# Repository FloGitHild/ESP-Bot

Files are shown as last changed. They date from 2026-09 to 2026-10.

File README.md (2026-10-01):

# ESP32-Kettenroboter

Ein modularer Kettenroboter als MINT-Lernprojekt: Schülerinnen und Schüler
sollen Aufbau, Sensorik und Programmierung eines mobilen Roboters kennenlernen.
Das Projekt verbindet ein Robotik-Konzept mit KiCad-Entwürfen und ersten
Arduino-Testprogrammen.

> **Projektstand:** Dieses Repository dokumentiert ein Konzept und begonnene
> Hardware-Entwicklung. Die beschriebenen Funktionen sind nicht automatisch
> als fertig aufgebaut, vollständig programmiert oder praktisch validiert zu
> verstehen. Insbesondere ist hier noch keine vollständige Fahr- und
> Autonomiesoftware enthalten.

## Konzept

Der geplante Roboter soll Hindernisse erkennen, Linien verfolgen, Abstände und
Fahrdaten erfassen und Daten per WLAN weitergeben. Das Konzept sieht vor, bis zu
20 möglichst gleiche Einheiten für den MINT-Unterricht aufzubauen.

Wesentliche Bausteine der beschriebenen Architektur:

- **Zwei Controller:** Ein ESP32-WROOM-32E übernimmt die übergeordnete Logik,
  Sensorik und WLAN-Kommunikation. Ein Arduino Pro Micro ist für zeitkritische
  Motorsteuerung, Encoder und Signaltöne vorgesehen.
- **Kettenantrieb:** Zwei N20-Getriebemotoren mit Encodern werden über einen
  Motortreiber angesteuert.
- **Sensorik:** Ein HC-SR04 für die Hinderniserkennung vorn, zwei VL53L0X für
  seitliche Abstandsmessung, ein TCS34725 für die Linienerkennung und eine
  LSM6DSOX-IMU für Beschleunigungs- und Drehratenmessung.
- **Erweiterbarer I²C-Bus:** Ein TCA/PCA9548A-Multiplexer soll Sensoren mit
  gleicher I²C-Adresse voneinander trennen. Ein zusätzlicher Anschluss am
  Gehäusedeckel ist für externe I²C-Module vorgesehen.
- **Rückmeldung und Aufzeichnung:** OLED, WS2812-LEDs und Piezo dienen der
  Ausgabe; eine microSD-Karte ist für Sensor- und Fahrdaten vorgesehen.
- **Energieversorgung:** Das Konzept beschreibt einen 1S-LiPo-Akku mit
  getrennten Boost-Versorgungen für Motoren und Logik.

Die detaillierte Beschreibung, Pin- und Busbelegungen, Stückliste sowie
Kostenschätzungen stehen in den Konzeptunterlagen. Werte daraus sind
Planungsangaben und müssen vor dem Aufbau anhand der verwendeten Bauteile
überprüft werden.

## Inhalt des Repositorys

| Pfad | Inhalt |
| --- | --- |
| [`Kettenroboter_Konzept_V1.0.html`](Kettenroboter_Konzept_V1.0.html) | Ausführliche Konzeptbeschreibung mit Architektur, Sensorik, Versorgung, Pinplan und Kalkulation |
| [`Kettenroboter_Konzept_V1.0.docx`](Kettenroboter_Konzept_V1.0.docx) | Bearbeitbare Fassung des Konzepts |
| [`Kettenroboter - Konzept V1.0.pdf`](Kettenroboter%20-%20Konzept%20V1.0.pdf) | PDF-Fassung des Konzepts |
| [`KICAD/Platine_V1.0/`](KICAD/Platine_V1.0/) | KiCad-Schaltplan- und Platinenprojekt V1.0 |
| [`Arduino Codes/`](Arduino%20Codes/) | Arduino-Sketche für einzelne Hardwaretests |
| [`Datenblätter/`](Datenbl%C3%A4tter/) | Datenblätter und ESP32-Maßzeichnung |
| [`Teilliste.xlsx`](Teilliste.xlsx) | Bauteil- und Bestellübersicht |
| [`Neue Notiz 09-22-2026.pdf`](Neue%20Notiz%2009-22-2026.pdf) | Zusätzliche Projektnotiz |

## Arduino-Testsketche

Die Sketche testen einzelne Baugruppen und sind kein zusammenhängendes
Roboterprogramm:

| Sketch | Zweck |
| --- | --- |
| [`IIC_Bus_Scanner.ino`](Arduino%20Codes/IIC_Bus_Scanner/IIC_Bus_Scanner.ino) | Sucht I²C-Geräte direkt und an den Kanälen eines Multiplexers |
| [`IIC_MUX_Test.ino`](Arduino%20Codes/IIC_MUX_Test/IIC_MUX_Test.ino) | Prüft Multiplexer, Buspegel und Kanalwahl |
| [`MUX_Test.ino`](Arduino%20Codes/MUX_Test/MUX_Test.ino) | Weiterer Multiplexer-Test |
| [`OLED_Direct_Test.ino`](Arduino%20Codes/OLED_Direct_Test/OLED_Direct_Test.ino) | Initialisiert ein OLED und zeigt Beispieltexte an |

Die Sketche verwenden derzeit SDA an GPIO 15 und SCL an GPIO 16. Im
Konzept-Pinplan ist der I²C-Hauptbus dagegen auf GPIO 21/22 vorgesehen.
Vor dem Anschließen oder Ausführen daher die tatsächliche Verdrahtung, den
jeweiligen Sketch und den passenden ESP32-Pinplan miteinander abgleichen.
Der OLED-Test verwendet die Bibliothek **Adafruit_SSD1306**.

## Sicherheit und Prüfung

Der Entwurf umfasst einen Lithium-Polymer-Akku, Ladeelektronik, DC/DC-Wandler
und Motoren. Vor einem Aufbau oder Ladebetrieb müssen insbesondere Akku,
Ladeschaltung, Schutzfunktionen, Leitungsquerschnitte und Strombelastbarkeit
für die tatsächlich ausgewählten Komponenten geprüft werden. Lithium-Akkus
nicht unbeaufsichtigt oder entgegen den Herstellerangaben laden.

ESP32-GPIOs sind nicht 5-V-tolerant. Für den im Konzept vorgesehenen HC-SR04
muss insbesondere das Echo-Signal auf einen zulässigen ESP32-Pegel angepasst
werden. Maßgeblich sind die Datenblätter der konkret eingesetzten Bauteile.

## Urheberschaft und Nutzung

Die eigenen Projektideen, konzeptionellen Entscheidungen und Ausarbeitungen
dieses Projekts stammen von **Florian (GitHub: [FloGitHild](https://github.com/FloGitHild))**.
Sie dürfen nur verwendet, bearbeitet oder weiterverbreitet werden, wenn
**Florian (FloGitHild) klar als Urheber genannt wird**. Eine Nutzung ohne diese
Namensnennung ist nicht gestattet.

Die Namensnennung ist keine pauschale Lizenz für Inhalte Dritter. Datenblätter,
Herstellerangaben, Produktnamen und sonstige übernommene Materialien
unterliegen weiterhin den Rechten und Bedingungen ihrer jeweiligen
Rechteinhaber. Für solche Inhalte gelten die jeweiligen Lizenz- und
Nutzungsbedingungen.

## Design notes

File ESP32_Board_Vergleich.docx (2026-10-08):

# ESP32-Boards im Vergleich – Auswahl für den Kettenroboter

Ziel: Ein gängiges, in Serie (ab 100 Stück) beschaffbares ESP32-Board finden, das neben der bestehenden Sensorik (HC-SR04, 2× VL53L0X, TCS34725, LSM6DSOX, OLED, microSD, WS2812, I²C-Multiplexer) noch Reserven für Erweiterungen hat: zweites Kameramodul, 5-Achsen-Roboterarm, weitere Farbsensoren und zusätzliche Mikrocontroller am I²C-Bus.

# 1. Anforderungen aus dem Konzept

- WLAN-Kommunikation (Datenübertragung), Bluetooth optional.
- Mehrere I²C-Geräte (Multiplexer TCA/PCA9548A, Sensoren, OLED, externe Module, weitere Mikrocontroller).
- SPI für microSD, 1-Wire-ähnliche Datenleitung für WS2812, Trigger/Echo für HC-SR04, Piezo, UART zum Arduino Pro Micro.
- Reserve-GPIOs und Rechenleistung für Kamera(s) und Servo-/Arm-Steuerung (z. B. über PCA9685 am I²C).
- Verfügbarkeit in großen Stückzahlen (20 Roboter plus Ersatz, Ziel: 100 Stück) zu einem für den Unterricht tragbaren Preis.

# 2. Vergleichstabelle gängiger ESP32-Boards

Board | SoC / Modul | CPU | Flash / PSRAM | Funk | Nutzbare GPIO* | Kamera | USB / Besonderheit | Eignung für Erweiterungen | Preis/Stk. bei ~100 Stk.**
ESP32-DevKitC V4 (WROOM-32E) – im Konzept vorgesehen | ESP32 (WROOM-32E) | 2× Xtensa LX6, 240 MHz | 4 MB / – | WLAN b/g/n, BT 4.2 + BLE | ~25 | Nur extern (I2S/Parallel, umständlich) | USB-UART (CP2102), 38 Pins, Standard-Footprint | Gut für aktuelles Konzept; wenig RAM (520 KB), knapp für Kamera | ca. 4–9 € (Klone 3–5 €, Original Espressif 8–10 €)
ESP32-DevKitC-VE (WROVER-E) | ESP32 (WROVER-E) | 2× LX6, 240 MHz | 4–8 MB / 8 MB | WLAN b/g/n, BT 4.2 + BLE | ~22 (GPIO16/17 für PSRAM belegt) | Ja (OV2640 möglich) | Pinkompatibel zu DevKitC V4 | Gut: PSRAM für Bildpuffer, gleiche Platine nutzbar | ca. 9–14 €
ESP32 DevKit V1 (DOIT, 30/38 Pin, Klon) | ESP32 (WROOM-32) | 2× LX6, 240 MHz | 4 MB / – | WLAN b/g/n, BT 4.2 + BLE | ~25 | Nein | USB-UART (CP2102/CH340); Qualität schwankt | Wie DevKitC, günstig, aber uneinheitliche Pinouts/Qualität | ca. 3–5 €
ESP32-S3-DevKitC-1 (N8R8 / N16R8) | ESP32-S3 (WROOM-1) | 2× Xtensa LX7, 240 MHz, Vektorbefehle (KI) | 8–16 MB / 8 MB (Octal) | WLAN b/g/n, BT 5 (LE) | ~30 (GPIO 35–37 bei Octal-PSRAM belegt) | Ja (DVP-Kameraschnittstelle, OV2640/OV5640) | 2× USB-C (nativ + UART), 44 Pins | Sehr gut: viel RAM, schnell, mehr Peripherie | ca. 7–15 € (Klone 6–9 €, Original 10–15 €)
Seeed XIAO ESP32S3 Sense | ESP32-S3 | 2× LX7, 240 MHz | 8 MB / 8 MB | WLAN, BT 5 | ~11 (kleine Bauform) | OV2640 mit Mikro, steckbar | USB-C, LiPo-Laden, 21×17,8 mm | Gut als zusätzliches Kameramodul; zu wenig Pins als Hauptcontroller | ca. 12–16 €
ESP32-S3-CAM (z. B. Freenove / Generic N16R8) | ESP32-S3 (WROOM-1) | 2× LX7, 240 MHz | 16 MB / 8 MB | WLAN, BT 5 | ~10 frei | OV2640/OV5640 integriert | USB-C, microSD-Slot | Ideal als 2. Kameramodul (I²C/UART-Slave), nicht als Hauptboard | ca. 10–18 €
ESP32-CAM (AI Thinker) | ESP32 (WROVER) | 2× LX6, 240 MHz | 4 MB / 4 MB | WLAN, BT 4.2 | ~8 frei (SD teilt Pins) | OV2640 | Kein USB (Programmieradapter nötig), microSD | Nur als Zusatz-Kameramodul; Programmierung aufwändig | ca. 5–9 €
ESP32-C3-DevKitM-1 / Super Mini | ESP32-C3 | 1× RISC-V, 160 MHz | 4 MB / – | WLAN, BT 5 (LE) | ~13 | Nein | USB nativ (Serial/JTAG), sehr klein | Zu schwach/wenig Pins für Hauptcontroller; gut als Sensor-Nebenknoten | ca. 2–5 €
ESP32-S2 Mini / DevKitM-1U | ESP32-S2 | 1× LX7, 240 MHz | 4 MB / 2 MB | Nur WLAN (kein BT) | ~28 | Eingeschränkt | USB OTG nativ | Veraltet gegenüber S3, nur für Sparprojekte | ca. 3–6 €
ESP32-C6-DevKitC-1 | ESP32-C6 | 1× RISC-V, 160 MHz (+LP-Kern) | 8 MB / – | WLAN 6 (ax), BT 5, Zigbee/Thread | ~22 | Nein | 2× USB-C | Modern, aber nur ein Kern und kein PSRAM; keine Kamera | ca. 7–11 €
LOLIN S3 / S3 Pro (WEMOS) | ESP32-S3 | 2× LX7, 240 MHz | 16 MB / 8 MB | WLAN, BT 5 | ~25 | Ja | USB-C, LiPo-Ladeschaltung, Qwiic/Stemma-Stecker (S3 Pro) | Sehr gut: ähnlich DevKitC-1, plus Akkuladen, Steckverbinder | ca. 8–13 €
Adafruit Feather ESP32 V2 / ESP32-S3 | ESP32 / ESP32-S3 | LX6 oder 2× LX7 | 8 MB / 2 MB (V2: 2 MB PSRAM) | WLAN, BT | ~21 | Nein (extern) | LiPo-Laden, STEMMA-QT, Hochwertig | Gut, aber teuer; Mengenpreis für 100 Stk. kaum günstiger | ca. 15–22 €

* Ungefähre Anzahl frei nutzbarer GPIOs ohne Flash/PSRAM/Boot-Pins, die je nach Variante abweichen.
** Richtwerte netto, Stand der Marktrecherche (Annahme: Bestellung ab 100 Stück über Distributoren wie Mouser, DigiKey, LCSC, Berrybase, Eckstein oder direkt bei Herstellern/AliExpress). Preise schwanken stark und sind vor Bestellung per Angebot zu prüfen. Grün markiert: Empfehlung.

# 3. Preisspannen im Überblick (Einzelboard, ~100 Stück)

Kategorie | Preisspanne | Boards
Budget (Klone, Standard-ESP32) | ca. 2–6 € | DevKit V1, DevKitC-Klone, C3 Super Mini, S2 Mini
Mittelklasse (Original/gute Klone, S3) | ca. 6–15 € | DevKitC V4, DevKitC-VE, S3-DevKitC-1, C6-DevKitC-1, LOLIN S3, ESP32-CAM, S3-CAM
Premium (Marken, Zusatzfunktionen) | ca. 12–22 € | XIAO ESP32S3 Sense, Adafruit Feather

Bei 20 Robotern entspricht das einem Mehrpreis von rund 100–200 € Gesamtkosten für ein S3-Board anstelle des WROOM-32E – bei deutlich mehr Leistungsreserven.

# 4. Kernunterschiede

- ESP32 (klassisch, WROOM/WROVER): Zwei Kerne mit 240 MHz, sehr verbreitet, viele Bibliotheken, 520 KB RAM. Ohne PSRAM sind Kameras kaum sinnvoll, mit WROVER aber möglich. Bluetooth Classic nur hier.
- ESP32-S3: Schneller Dual-Core (LX7) mit KI-Vektorbefehlen, natives USB, BT 5, bis zu 16 MB Flash und 8 MB Octal-PSRAM, hardwareseitige Kameraschnittstelle sowie mehr GPIOs. Deutlich bessere Wahl für Kamera und Multitasking.
- ESP32-C3 / C6: Einkern-RISC-V, günstig, modern (BT 5, WLAN 6 beim C6), aber ohne Kamera-Eignung und mit weniger Pins. Geeignet als Nebenknoten, nicht als Hauptcontroller.
- ESP32-S2: Nur WLAN, Einkern; durch S3 praktisch überholt.
- Kamera-Boards (ESP32-CAM, S3-CAM, XIAO Sense): Kompakt mit Sensor, aber kaum freie Pins – ideal als separate Kameramodule, die per UART/I²C/WLAN Daten liefern.
- Qualität: Originale (Espressif, Seeed, Adafruit) sind bei 100 Stück meist nur 10–30 % teurer als Klone, dafür einheitlicher (Pinout, Spannungsregler, USB-Chip) – wichtig für 20 baugleiche Roboter.

# 5. Fazit und Empfehlung

Empfehlung: ESP32-S3-DevKitC-1-N16R8 (Espressif, ESP32-S3-WROOM-1, 16 MB Flash, 8 MB Octal-PSRAM). Alternativ gleichwertig: LOLIN S3 (16 MB / 8 MB). Richtpreis: ca. 7–15 € pro Stück bei 100 Stück.

Warum dieses Board?

- Leistung: Dual-Core 240 MHz, 8 MB PSRAM – genug für Kamerabild, WLAN-Streaming, Datenlogging und Sensorfusion parallel.
- Kamera: Native DVP-Kameraschnittstelle; eine Kamera direkt am Board, eine zweite als eigenständiges Kameramodul (ESP32-S3-CAM oder XIAO Sense), das per WLAN, UART oder I²C angebunden wird.
- Roboterarm (5 Achsen): Servos über einen PCA9685 (16-Kanal-PWM, I²C) ansteuern – nur zwei GPIOs am ESP32 nötig. Servos benötigen eine eigene 5–6-V-Versorgung mit ausreichend Strom (nicht über den Board-Regler).
- Farbsensoren und weitere I²C-Geräte: Über den bereits geplanten TCA9548A lassen sich 8 Kanäle mit je eigenen gleichen Adressen betreiben; der S3 bietet zwei I²C-Controller und kann zusätzlich als Master für weitere Mikrocontroller dienen.
- Weitere Mikrocontroller: Arduino Pro Micro (bereits vorgesehen) per UART; weitere Knoten per I²C (ESP32 als Master) oder WLAN/ESP-NOW.
- Zukunftssicher: BT 5, natives USB (Debugging und Programmierung ohne Zusatzchip), breite Community-Unterstützung.

Wichtige Hinweise zur Umsetzung:

- Der S3-DevKitC-1 hat ein anderes Pinout und eine andere Bauform (2×22 Pins) als der DevKitC V4 – die KiCad-Platine müsste angepasst werden. Wer die vorhandene Platine unverändert nutzen will, wählt das ESP32-DevKitC-VE (WROVER-E, ca. 9–14 €) mit PSRAM, behält aber nur die ältere Kernarchitektur.
- Bei den Octal-PSRAM-Varianten (N8R8, N16R8) sind GPIO 35, 36 und 37 intern belegt und nicht nutzbar; Pinbelegung vor dem Platinen-Redesign anhand der Espressif-Dokumentation prüfen.
- Strombedarf: WLAN-Spitzen mit Kamera können über 500 mA erreichen; Logikversorgung (Boost aus 1S-LiPo) entsprechend dimensionieren.
- Vor der Großbestellung 2–3 Muster verschiedener Lieferanten testen und ein verbindliches Angebot für 100 Stück einholen.

Hinweis: Die Preise sind Richtwerte aus allgemeiner Marktkenntnis, nicht aus einer tagesaktuellen Abfrage, und ändern sich häufig.

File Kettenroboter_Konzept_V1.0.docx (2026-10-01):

# Kettenroboter mit ESP32-WROOM-32E

Konzept V1.0 - Idee · Aufbau · Teilliste · Datenblatt

Stand: 28.09.2026 · Bestellung: Dezember 2026 · 20 Stück · 1S LiPo 3,7V 10.000mAh (Fertig-Pack) · Prototyp V1.0

# 1. Idee

## 1.1 Was soll der Roboter können?

Ein Kettenroboter für den MINT-Unterricht, der selbstständig Hindernisse erkennt, Linien folgt, Strecken misst und über WiFi Daten weitergibt. 20 identische Einheiten sollen gebaut und programmiert werden – jeder Schüler erhält einen Roboter zum Selbstbau.

- Hinderniserkennung vorn: HC-SR04 Ultraschall misst 3-400cm über Trig/Echo-Puls – Schüler lernen Schallgeschwindigkeit und Laufzeitberechnung
- Abstand seitlich: 2× VL53L0X ToF (links/rechts) für Wandabstand und Linienführung
- Linienverfolgung: TCS34725 Farbsensor erkennt schwarze Linien auf hellem Untergrund
- Erweiterung: 4-pol. I²C-Buchse an der Oberfläche (Deckel) führt den Bus nach außen – externe Module (BME280 etc.) einfach einstecken, freier MUX-Kanal K5
- Lage/Drift: LSM6DSOX IMU (Beschleunigung + Gyroskop) für Selbstausrichtung
- Steuerung: ESP32 (WiFi, Logik, Sensorik) + Arduino Pro Micro (Echtzeit: Motor-PWM, Encoder, Töne)
- Feedback: WS2812 LED-Strip (Statuslicht) + OLED-Display (Messwerte) + Piezo (Signaltöne)
- Datenaufzeichnung: microSD-Karte speichert Sensor- und Fahrdaten

## 1.2 Warum diese Architektur?

Entscheidung | Begründung | Lerninhalt
ESP32 + Arduino (zwei CPUs) | ESP32 für WiFi/Sensorik, Arduino für Echtzeit-Motorsteuerung | Arbeitsteilung, I²C-Kommunikation, Adressierung
I²C-Bus mit TCA9548A | Alle Sensoren an 2 Pins, trotz gleicher Adressen | Bussysteme, Multiplexer, Adresskonflikte
Ultraschall (HC-SR04) statt ToF vorn | Direkte GPIO-Ansteuerung, kein Chip nötig | Laufzeitmessung, Schallgeschwindigkeit, PWM
1S LiPo 3,7V 10Ah (Fertig-Pack) | Einzelzelle = kein Zellausgleich, keine Balance-Ladung, einfachste Lithium-Technik – 10Ah trotzdem ~6-7h Laufzeit | Lithium-Sicherheit, CC/CV-Laden, Kapazität vs. Laufzeit
2× MT3608 Boost (6V + 5V) | Aus 3,0-4,2V konstant 6V für Motoren und 5V für Logik – unabhängig vom Akkustand, Eingang ab 2V (bis tief in die Entladung) | DC/DC-Wandler (Boost statt Buck), Poti-Einstellung, Effizienz
DRV8833 Treiber | Fast ohne Spannungsabfall (360mΩ) → 6V kommen am Motor an, 95% Effizienz, kein Kühlkörper | H-Brücke, PWM, Freilauf/Bremse
TP4056 USB-C Lademodul | CC/CV-Ladung 4,2V/1A mit Schutzschaltung (Über-/Unterladung, Kurzschluss) – 0,59€ ab 20 Stück, Laden per handelsüblichem USB-C | CC/CV-Ladephasen, Ladestrom vs. Kapazität (0,1C), Schutzschaltungen
Female-Header | Alle 24 freien GPIOs steckbar – kein Löten für Addons | Erweiterbarkeit, Pinbelegung

## 1.3 Steckdose auf einen Blick

ESP32-WROOM-32E (WiFi+BT) + Arduino Pro Micro (Echtzeit)

I²C (IO21/IO22) · SPI (IO18/19/23/26) · GPIO (IO16/17) · I²C-Port am Deckel (K5)

2× N20 6V 1000RPM + DRV8833 (6V vom Boost → ~6V am Motor)

HC-SR04 · 2× VL53L0X · TCS34725 · LSM6DSOX · OLED

1S LiPo 3,7V 10Ah → 2× MT3608 Boost (6V/5V) → alles · Lader: USB-C TP4056

24 GPIOs auf Female-Header für Addons

ca. 160 × 160 × 100 mm

ca. 800 g (geschätzt)

# 2. Aufbau

## 2.1 Stromversorgung (Schaltplan)

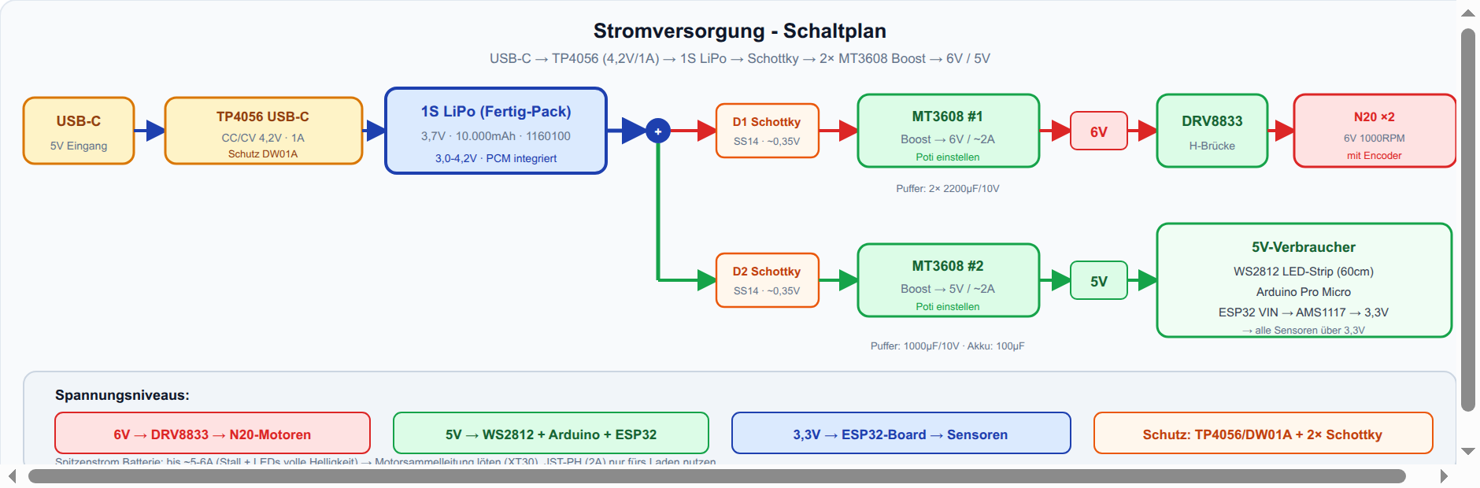
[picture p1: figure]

- Ladung:TP4056 USB-C Lademodul (https://www.roboter-bausatz.de/p/tp4056-1a-lithium-ionen-lipo-lademodul-fuer-arduino-usb-c) (CC/CV, 4,2V/1A, integrierter DW01A-Schutz: Über-/Unterladung + Kurzschluss; rot=lädt, grün=voll). Staffelpreis: 0,59€ ab 20 Stück – Alternativen: makeroo 3er-Set 1,79€ (https://makeroo.de/products/3er-set-tp4056-5v-1a-usb-c-lademodul-18650-lithium-akkuladeboard-mit-schutzschaltung), Pollin 1,75€ ab 10 (https://www.pollin.de/p/daypower-lademodul-fuer-lithium-akkus-m-ll-tp4056-351427). Bei 1S entfallen Balance-Ladung und Zellausgleich komplett.
- Akku: 1× flache Zelle 3,7V 10.000mAh (1160100, 11×60×100mm) mit integrierter PCM-Schutzplatine, ~160-200g. Einzelzelle = keine Reihenschaltung, keine BMS-Balancelogik nötig. Vorsicht: die JST-PH-Steckverbindung ist nur fürs Laden geeignet (2A) – Motorsammelleitung direkt löten oder XT30 verwenden (Spitzen bis ~6A).
- 6V Boost: MT3608 (Eingang 2-24V, internes 4A-Schaltstrom-Limit, ~93% Wirkungsgrad) lädt die Ausgangs-Spannung auf konstant 6V – Motoren laufen unabhängig vom Akkustand. Durch den geringen Abfall des DRV8833 (360mΩ) kommen ~5,7-6V am Motor an → volles Drehmoment. Kein Kühlkörper nötig.
- 5V Boost: zweiter MT3608 → WS2812, Arduino und ESP32-VIN. Das ESP32-Board wandelt intern (AMS1117) auf 3,3V für sich und alle Sensoren.
- Puffer-Kondensatoren: 2× 2200µF/10V (6V-Schiene), 1000µF/10V (5V-Schiene), 100µF (Akku) glätten die ms-weisen Lastspitzen von PWM/Motoren – ΔV = I·t/C, also ~5ms Puffer bei 1A und 4700µF. Der Boost selbst regelt die Sekundenlast; die Kondensatoren fangen nur die Schaltspitzen ab.
- Schottky-Dioden (D1/D2): 2× SS14 (1A/40V) oder SS54 (5A) zwischen Akku und den Boost-Eingängen – Polaritäts- und Ladeschutz, Entkopplung der Schienen. Der ~0,35V Abfall ist unkritisch, da der MT3608 schon ab 2V Eingang arbeitet (auch tief entladene Zelle 3,0V − 0,35V = 2,65V).
- Nicht genutzt – und warum: XL6009-Booster brauchen laut Datenblatt ≥3,6V Eingang und würden schon vor Ende der Entladung abschalten; Buck-Wandler (MP2338, LM2596) wären die falsche Topologie, da die Zelle unter der Rails-Spannung liegt. Bei 1S ist Boost die einzige sinnvolle Wahl.

Die PCM der Zelle und der DW01A des Lademoduls begrenzen den Entladestrom typischerweise auf 2-3A. Beim Starrfahren können die Motorspitzen darüber liegen – die Schutzschaltung schaltet kurz ab und erholt sich lastfrei (schützendes Verhalten, kein Schaden). Alternativ: Pack mit höherer PCM-Schwelle wählen oder Motorstrom per PWM begrenzen. Zusätzlich begrenzt der MT3608 (4A-Schaltstrom) und die DRV8833-Überlastschaltung den Strom – es kann also nichts durchbrennen, die Motoren werden im Worst Case nur weich abgebremst.

## 2.2 Bus-Architektur (I²C + SPI + GPIO)

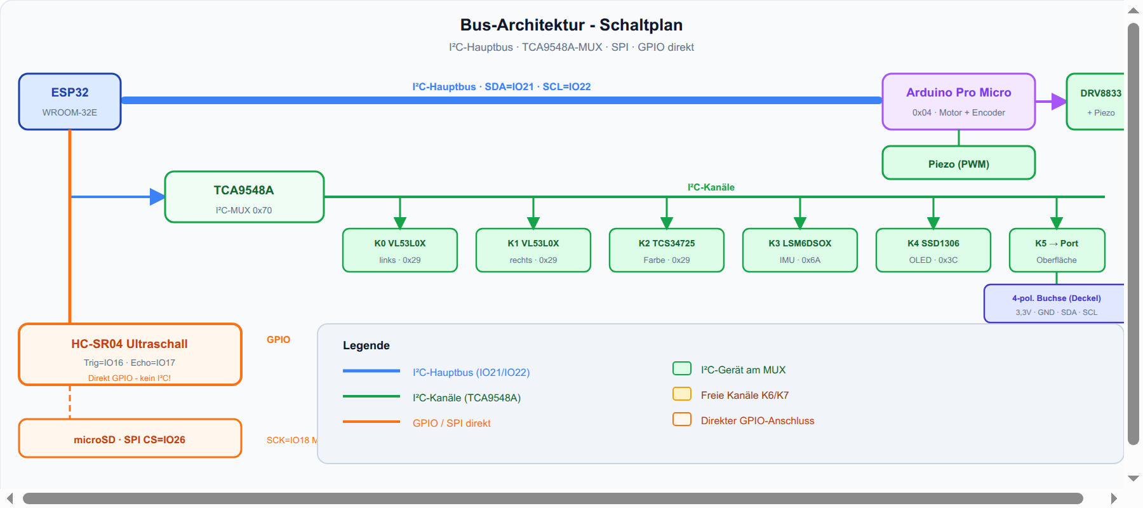
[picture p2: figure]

I²C-Adressen: TCA9548A=0x70 · VL53L0X=0x29 (K0+K1) · TCS34725=0x29 (K2) · LSM6DSOX=0x6A (K3) · SSD1306=0x3C (K4). Nicht belegt: z.B. 0x20-0x28, 0x38-0x3B, 0x3D-0x3F, 0x6B-0x6F, 0x71-0x77. HC-SR04: kein I²C - direkt GPIO, 40kHz, 3-400cm; Echo kommt mit 5V → Spannungsteiler 10kΩ/20kΩ vor IO17 (ESP32-GPIOs sind nicht 5V-tolerant!).

Versorgung: Alle I²C-Sensoren laufen mit 3,3V direkt vom ESP32-Board (Board-Regler AMS1117, Eingang 5V) – Gesamtverbrauch nur ~60mA, daher ist kein dritter Wandler nötig. Ein separater 3,3V-Wandler wäre nur nötig bei >800mA Sensorlast oder als entkoppelte Rausch-Schiene.

Oberflächen-Port (K5): 4-pol. Buchse auf dem Deckel (3,3V · GND · SDA · SCL) führt den I²C-Bus nach außen – für externe Module (BME280, Lichtsensor, Erweiterungen) ohne Löten. Angeschlossen an den freien MUX-Kanal K5: externe Geräte sind vom Hauptbus isoliert, daher keine Adresskonflikte mit den Bord-Sensoren (gleiche Adresse 0x29 z.B. möglich). Software: tca.selectChannel(5). K6/K7 bleiben zusätzlich frei. Alternative Verdrahtung: Port direkt auf IO21/IO22 (Hauptbus) – dann nur Geräte ohne Adresskonflikt verwenden.

## 2.3 Pin-Plan ESP32 (34 GPIO)

### Feste Belegung (10 Pins)

GPIO | Funktion | GPIO | Funktion
IO21 | I2C SDA (alle Sensoren, OLED) | IO22 | I2C SCL
IO18 | SPI SCK (microSD) | IO19 | SPI MISO
IO23 | SPI MOSI | IO26 | SPI CS_SD
IO1 | WS2812-Daten | IO5 | Strapping (digital)
IO16 | HC-SR04 Trig | IO17 | HC-SR04 Echo (über Spannungsteiler 10kΩ/20kΩ!)

### Encoder + Motor → Arduino Pro Micro

Arduino Pin | Funktion | Bemerkung
Pin 2, 4 | Encoder 1 A/B | HAT-Interrupt + PCINT
Pin 7, 8 | Encoder 2 A/B | PCINT
Pin 3, 6 | DRV8833 AIN1 / AIN2 (Motor links) | PWM: Richtung + Geschwindigkeit
Pin 5, 9 | DRV8833 BIN1 / BIN2 (Motor rechts) | PWM: Richtung + Geschwindigkeit
Pin 10 | Piezo Speaker | PWM / Tone
A4 / A5 | I²C (gemeinsam mit ESP32) | Adresse 0x04

Encoder-Abfrage und Motor-PWM brauchen Echtzeit-Interrupts. Der ESP32 kümmert sich um WiFi, I²C, SPI und Sensoren. Der Arduino empfängt I²C-Befehle (z.B. "MOTOR:150:200") und steuert Motoren + Töne. IO16/IO17 bleiben für den Ultraschallsensor frei.

### Freie GPIOs (24 Pins) → Female-Header

Alle 24 freien Pins stehen auf einer Female-Header-Leiste für Addons - kein Löten nötig.

GPIO | Typ | GPIO | Typ
IO0 | Strapping (BOOT) | IO2 | Strapping
IO3 | digital | IO4 | Strapping
IO12 | Strapping (VDD_SDIO) | IO13 | digital
IO14 | digital | IO15 | Strapping
IO20, IO24 | digital | IO25 | DAC1 / ADC2
IO27 | TOUCH7 / ADC2 | IO28-31 | digital
IO32, IO33 | TOUCH + ADC1 | IO34-39 | ADC1 (input-only)

Orange = Strapping-Pin (Boot-Level beachten!). Ergebnis: 34 GPIO gesamt - 10 fest = 24 frei.

## 2.4 Treibermodul-Vergleich: DRV8833 vs L298N

Merkmal | DRV8833 (gewählt) | L298N (Alternative)
Technologie | N-MOSFET | Bipolar (BJT)
Spannung | 2,7-10,8V (passt zur 6V-Schiene) | 5-46V (nur sinnvoll ab 2S – bei 1S ungeeignet)
Strom/Kanal | 1,2A (dau), 2A (Spitze) | 2A (dau), 3A (Spitze)
Spannungsabfall | ~0,2V (360mΩ) | ~1,4-2V (heiß!)
Spannung am Motor | ~5,8-6V → volles Drehmoment | ~4,2V (-30%)
Effizienz | ~95% | ~70%
Kühlkörper | Nicht nötig | Nötig (>0,5A)
Strombegrenzung | integriert (Schutz vor Überlast) | keine
Steuerung | 2 IN-Pins pro Motor, PWM = Tempo, kein EN | 2 Richtungs + 1 EN-Pin
Preis | 6,55 € (BerryBase) | 2,30 € (Reichelt)
Dokumentation | Gut (TI-Datenblatt + Adafruit/Pololu) | Extrem breit (Tutorials)
Fazit | Gewählt: 6V am Motor, effizient, kühl | Billiger, aber ~1,5V + Wärme verloren

### Steuertabelle DRV8833 (je Motor)

IN1 | IN2 | Funktion
0 | 0 | Freilauf – Ausgänge Hi-Z, Motor rollt aus
1 | 1 | Bremse – Kurzschluss, schneller Stop
1 | 0 | Vorwärts (bei vertauschten Motordrähten gedreht)
0 | 1 | Rückwärts
PWM | 0 | Vorwärts + Geschwindigkeit (duty = Tempo), bei 0 → freilaufen

Belegung: Motor links = AIN1 (Pin 3) / AIN2 (Pin 6), Motor rechts = BIN1 (Pin 5) / BIN2 (Pin 9) – alle PWM-fähig. SLEEP muss HIGH sein (Modul-Pull-up). Günstige Alternative: L298N für 2,30 € (Reichelt) (https://www.reichelt.de/de/de/shop/produkt/entwicklerboards_-_motorsteuerung_2-fach_l298n-282644) – dann aber nur ~4,2V am Motor, Kühlkörper, ENA/ENB-Pins und ≥5V Schiene nötig (bei 1S-Strompfad also ungeeignet).

# 3. Teilliste

Alle Händler: deutsche/EU-Anbieter, Stand: 28.09.2026. Preise inkl. MwSt., Staffelpreise eingerechnet (Mengenrabatte für 20 Roboter), Versandkosten nicht enthalten. Pro Bauteil mindestens zwei Quellen – die günstigste Variante steht vorne.

## 3.1 Komponenten pro Roboter (1×)

# | Komponente | Kurzdaten | Preis | Quellen (Links) | Staffel

1 | ESP32-WROOM-32E | 240MHz, WiFi+BT, 34 GPIO, USB-C | 11,20 € | Reichelt (https://www.reichelt.de/de/de/shop/produkt/entwicklungsboard_esp32-wroom-32e-341303) · Conrad 11,99€ (https://www.conrad.de/de/p/espressif-esp32-devkitc-32e-entwickler-platine-esp32-devkitc-32e-2814007.html) · Schukat (B2B ab ~7,79€ netto) (https://shop.schukat.com/de/de/EUR/Entwicklungstool-WLAN-Bluetooth/Espressif-Systems/ESP32-DEVKITC-32E/p/90255) | Staffel Schukat
2 | Arduino Pro Micro | ATmega32U4, 5V/16MHz, 18 GPIO | 8,75 € | Reichelt (JOY-IT) (https://www.reichelt.de/de/de/shop/produkt/arduino_kompatibles_micro_pro_board_atmega32u4_usb-330660) · Conrad (USB-C) (https://www.conrad.de/de/p/joy-it-ard-32u4-usb-c-arduino-board-atmega32-3588331.html) | -
3 | DRV8833 Treiber | Dual H-Bridge, 1,2A/ch, 360mΩ, PWM + Freilauf/Bremse | 6,55 € | BerryBase (Adafruit 3297) (https://www.berrybase.de/adafruit-drv8833-dc-stepper-motor-treiber-breakout-board) · Botland (Pololu 2130, 8,50€) (https://botland.de/dc-motortreiber/546-drv8833-zweikanal-motorsteuerung-108-v-12-a-pololu-2130-5904422367213.html) | -
4 | 2× N20 Motor+Encoder | 6V, 1000RPM, Hall-Encoder, Metall | ~18,98 € | HESTORE 9,49€/Stk (https://www.hestore.eu/de/prod_10042892.html) · Kamami ~11,50€ (https://kamami.pl/en/micro-metal-gearmotors/582334-1000rpm-6v-n20e-miniature-motor-with-gear-and-encoder-5906623459582.html) · AliExpress ~5-9€ | HESTORE 20+ = 7,98€ netto
5 | HC-SR04 Ultraschall | 3-400cm, 5V, Trig+Echo, ±3mm | 1,49 € | BerryBase (https://www.berrybase.de/hc-sr04-ultraschall-sensor) · roboter-bausatz (1,75€ ab 20, mit Winkel) (https://www.roboter-bausatz.de/p/hc-sr04-ultraschallsensor-mit-montagewinkel) · Funduino 1,74€ (https://funduinoshop.com/elektronische-module/sensoren/bewegungs-und-distanzsensoren/ultraschallsensor-entfernungssensor-hc-sr04) | rb ab 20: 1,75€
6 | 2× VL53L0X ToF | 30mm-2m, I2C 0x29 (links+rechts) | 7,20 € | Makershop GY-530 3,60€ (https://www.makershop.de/sensoren/distanz/gy-530-vl53l0x/) · Makershop (Adafruit) 14,85€ (https://www.makershop.de/sensoren/distanz/adafruit-vl53l0x/) · BerryBase (Pololu) 19,95€ (https://www.berrybase.de/pololu-vl53l0x-time-of-flight-distanzsensor-mit-spannungsregler-bis-200cm) | -
7 | TCA9548A MUX | 8 I²C-Kanäle, 0x70 | 2,30 € | BerryBase (https://www.berrybase.de/tca9548a-i2c-multiplexer-breakout-board) · Funduino 2,15€ (https://funduinoshop.com/elektronische-module/schnittstellen-konverter/signalwandler/tca9548a-i2c-multiplexer) · Reichelt 2,80€ (https://www.reichelt.de/de/de/shop/produkt/entwicklerboards_-_i2c-multiplexer_tca9548a-291436) | -
8 | LSM6DSOX IMU | 6-Achsen, 0x6A, ±16g/±2000dps | 11,90 € | BerryBase (Adafruit 4438) (https://www.berrybase.de/adafruit-lsm6dsox-6-dof-beschleugnigunssensor-und-gyroskop) · Adafruit 11,95$ (https://www.adafruit.com/product/4438) · eckstein 14,40€ (https://eckstein-shop.de/Adafruit-LSM6DSOX-6-DoF-Accelerometer-and-Gyroscope-STEMMA-QT-Qwiic) | -
9 | TCS34725 Farbsensor | RGB+Clear, IR-Filter, I2C, LED, 400kHz | 6,99 € | AZ-Delivery (https://www.az-delivery.de/en/products/tcs34725-rgb-color-sensor) (3er 13,99€ · 5er 19,99€ = 4,00€/Stk) | 5er-Set = 4,00€
10 | 0,96" OLED SSD1306 | 128×64, I2C 0x3C | 4,66 € | Funduino (https://funduinoshop.com/elektronische-module/displays/oled/oled-0.96-128x64-gvss-i2c) · Reichelt (JOY-IT) 6,99€ (https://www.reichelt.de/de/de/shop/produkt/entwicklerboards_-_display_0_96_oled-display_ssd1306-266107) · Reichelt (Soldered) 8,85€ (https://www.reichelt.de/de/de/shop/produkt/entwicklerboards_-_display_0_96_oled-display_ssd1306-372147) | -
11 | microSD-Modul | SPI, 3,3V/5V, bis 32GB | 1,40 € | BerryBase (https://www.berrybase.de/micro-sd-card-reader-modul-mit-spi-schnittstelle) · makeroo 1,19€ (https://makeroo.de/products/micro-sd-card-reader-modul-mit-spi-interface-fur-arduino) · Reichelt (Soldered) 3,99€ (https://www.reichelt.de/de/de/shop/produkt/entwicklerboards_-_breakout-board_fuer_microsd-karten-376529) | -
12 | WS2812-Strip 60cm | 5V, 60 LED/m, ~36 LED pro Roboter | ~2,24 € | Amazon (BTF 5m/300LED = 18,69€) (https://www.amazon.de/gp/aw/d/B088BPGMXB) · Reichelt (5m) 87,99€ (https://www.reichelt.de/de/de/shop/produkt/led-streifen_digital_rgb_300_leds_5_m_ws2812b-260971) | 12m gesamt = 3 Rollen
13 | Piezo-Summer | passiv, 5V, PWM | 1,20 € | Reichelt (https://www.reichelt.de/de/de/shop/produkt/entwicklerboards_-_summer_passiv-282662) · BerryBase (KY-006) (https://www.berry-base.com/ky-006-passives-buzzer-modul) | -
14 | LiPo 1S 3,7V 10Ah | flach 1160100 (11×60×100mm), PCM, ~160-200g, JST-PH | 19,79 € | Amazon (19,79€) (https://www.amazon.de/dp/B0CSS4FFHC) · Reichelt (22,80€) (https://www.reichelt.de/de/de/shop/produkt/li-ion_akku_soldered_333290_10000_mah_3_7_v-373554) · YDL (ab 10 Stk: 7,50$ ≈ 6,90€, +Versand/Zoll) (https://ydlbattery.com/products/1160100-10000mah-li-ion-battery) | YDL 10+: −25%
15 | TP4056 USB-C Lader | CC/CV 4,2V/1A, DW01A-Schutz, LED-Anzeige | 0,59 € | roboter-bausatz (0,59€ ab 20) (https://www.roboter-bausatz.de/p/tp4056-1a-lithium-ionen-lipo-lademodul-fuer-arduino-usb-c) · makeroo (3er 1,79€ = 0,60€) (https://makeroo.de/products/3er-set-tp4056-5v-1a-usb-c-lademodul-18650-lithium-akkuladeboard-mit-schutzschaltung) · Pollin (1,75€ ab 10) (https://www.pollin.de/p/daypower-lademodul-fuer-lithium-akkus-m-ll-tp4056-351427) | rb ab 20: −43%
16 | 2× MT3608 Boost | 2-24V ein, 4A Schaltstrom, einstellbar (6V + 5V) | 1,78 € | roboter-bausatz (0,89€ ab 20) (https://www.roboter-bausatz.de/p/spannungswandler-mt3608-dc-dc-step-up-modul-2a-2v-28v) · androegg 1,29€ (https://www.androegg.de/shop/mt3608-usb-micro-step-up-spannungs-voltage-konverter/) · eckstein 1,75€ (https://eckstein-shop.de/MT3608DC-DCAdjustableStep-upSpannungsreglerBoostVoltageRegulator2V-24VEN) | rb ab 20: −29%
17 | Schottky + Elkos + Widerstände | 2× SS14/SS54, 2×2200µF+1000µF+100µF, Teiler 10k/20k, Buchsen | ~2 € | Reichelt (https://www.reichelt.de/de/de/shop/produkt/schottkydiode_40_v_5_a_do-214ab_smc-146598) · BerryBase (https://www.berrybase.de/) | Widerstände/Elkos ggf. 50er-Packs
18 | Ketten-Chassis | Alu/Rahmen + Gummiketten, 6V-N20-kompatibel | 27,90 € | Botland (Black Gladiator) (https://botland.de/roboter-chassis/15103-black-gladiator-kettenroboterchassis-mit-antrieb-dfrobot-rob0153-6959420915026.html) · Funduino (TP101) 31,46€ (https://funduinoshop.com/werkstatt/bausaetze/chassis/stabiles-tank-chassis/kettenfahrzeug-tp101/roboter-kit-mit-12v-motoren-fuer-arduino-geeignet) · Amazon (Abaodam) (https://www.amazon.de/dp/B0FLWGYVQ2) · Botland (Devastator) 89,50€ (https://botland.de/roboter-chassis/6610-dfrobot-devastator-kettenroboter-chassis-metallmotoren-6959420910250.html) | Staffel prüfen
19 | PCB + Female Headers | Trägerplatine, Pinheader, Buchsen | 15-40 € | JLCPCB (https://jlcpcb.com/) · Eurocircuits (https://www.eurocircuits.com/) | 20-platten-Rabatt
Summe pro Roboter | ~150-235 € | Elektronik ~106€ · Chassis 28-90€ · PCB 15-40€

## 3.2 Massenbestellung 20 Roboter (Staffelpreise angewendet)

Komponente | Menge (20×) | Einzelpreis | Gesamt | Quelle / Rabatt
ESP32-WROOM-32E | 20 Stk | 11,20 € | 224,00 € | Reichelt (günstiger: Schukat B2B ~186€)
Arduino Pro Micro | 20 Stk | 8,75 € | 175,00 € | Reichelt JOY-IT
DRV8833 Treiber | 20 Stk | 6,55 € | 131,00 € | BerryBase (Botland Pololu: 170€)
N20 Motor+Encoder | 40 Stk | 9,49 € | 379,60 € | HESTORE Staffel 20+ (netto 7,98€); Ali-Variante ~240€
HC-SR04 | 20 Stk | 1,49 € | 29,80 € | BerryBase (100+ Lager)
VL53L0X ToF (GY-530) | 40 Stk | 3,60 € | 144,00 € | Makershop – statt 400€ (Adafruit) → −256€
TCA9548A MUX | 20 Stk | 2,30 € | 46,00 € | BerryBase (Funduino: 43€)
LSM6DSOX IMU | 20 Stk | 11,90 € | 238,00 € | BerryBase (Adafruit-Direktbestellung ähnlich)
TCS34725 | 4× 5er-Set | 4,00 €/Stk | 79,96 € | AZ-Delivery Staffel (5er = 19,99€)
OLED SSD1306 | 20 Stk | 4,66 € | 93,20 € | Funduino (Reichelt JOY-IT: 139,80€)
microSD-Modul | 20 Stk | 1,40 € | 28,00 € | BerryBase
WS2812-Strip (3×5m) | 15 m | 18,69 €/5m | 56,07 € | Amazon BTF-LIGHTING (Reichelt-Variante: 176€)
Piezo | 20 Stk | 1,20 € | 24,00 € | Reichelt
LiPo 1S 10Ah | 20 Stk | 19,79 € | 395,80 € | Amazon B0CSS4FFHC (YDL-Alt ab 10: ~137€ + Versand)
TP4056 USB-C | 20 Stk | 0,59 € | 11,80 € | roboter-bausatz Staffel ab 20 (−43%)
MT3608 Boost | 40 Stk | 0,89 € | 35,60 € | roboter-bausatz Staffel ab 20 (−29%)
Schottky/Elko/Widerstände | 20× Satz | ~2,00 € | 40,00 € | Reichelt/BerryBase
Ketten-Chassis | 20 Stk | 27,90 € | 558,00 € | Botland Black Gladiator (Funduino: 629€ · Devastator: 1.790€)
PCB + Female Headers | 20× | 15-40 € | 300-800 € | JLCPCB/Eurocircuits
Summe 20 Roboter | | | ~3.000-3.500 € | pro Stück: ~150-175 € (teure Chassis-Variante: ~200€)

Die größten Kostentreiber: LiPo (396€, ~19%), Chassis (558€, ~27%), N20 (380€), ESP32 (224€). Die Umstellung von 2S auf 1S spart nicht nur Akkuzellen (20 statt 40 Packs), sondern auch BMS und USB-2S-Lader – zusammen ~300-400€ weniger. Größter Einzelsparhebel: ToF-Sensoren als GY-530 statt Adafruit (−256€) und MT3608-Booster mit Staffelpreis statt teurer Ali-Module.

# 4. Datenblatt

## 4.1 Abmessungen & Gewicht

Parameter | Wert | Bemerkung
Bauform (Gesamt) | 160 × 160 × 100 mm | L × B × H (ca. 16×16×10 cm)
Chassis-Platte | ~150 × 150 × 3 mm | Aluminium, 2-mm-Rand für Ketten
Kettenlänge (je Seite) | ~150 mm | Gummikette, 9 Glieder
Bodenfreiheit | ~15 mm | ausreichend für Bodensensor
Gewicht geschätzt | ~800 g | siehe Aufschlüsselung unten

Bauteil | Gewicht (ca.)
Chassis (Alu-Platte 150×150×3mm) | 180 g
2× Gummiketten + Räder | 120 g
2× N20 Motor + Getriebe | 100 g
1× LiPo 3,7V 10Ah (1160100, flach) | 180 g
Elektronik (ESP32, Arduino, PCB, Sensoren) | 120 g
DRV8833 + 2× MT3608 + TP4056 + Verkabelung | 50 g
WS2812-Strip, OLED, microSD, Piezo, Schrauben | 50 g
Gesamt | ~800 g

## 4.2 Stromverbrauch & Laufzeit

Schiene | Verbraucher | Typ. mA | Spitze mA
6V (MT3608 #1) | 2× N20 Motor (Fahrt) | 200 | 1.100 (Stall)
DRV8833 (Iq + Logik) | 2 | 6
5V (MT3608 #2) | WS2812 Strip (60cm, dimm) | 360 | 1.800
ESP32 (WiFi aktiv, via VIN) | 280 | 350
Arduino Pro Micro | 30 | 50
HC-SR04 | 15 | 15
Piezo + Sensoren (über AMS1117) | 75 | 130
Schiene gesamt (Ausgang) | ≈ 4,7 W | ≈ 17,8 W
Batteriestrom (3,7V, η≈0,9) | ≈ 1,4 A | ≈ 6 A (bei 3,5V/η 0,85)

Szenario | Strom (Batterie) | Laufzeit (10.000 mAh)
Dauerfahrt + WS2812 volle Helligkeit | ≈ 3,6 A | ≈ 2,7 h
Dauerfahrt + WS2812 dimm (50%) | ≈ 1,4 A | ≈ 6-7 h
Dauerfahrt + LEDs aus | ≈ 0,85 A | ≈ 11 h
Standby (keine Motoren, WiFi, dimm) | ≈ 0,5 A | ≈ 20 h
Standby (keine Motoren, WiFi aus) | ≈ 0,2 A | ≈ 50 h
Deep-Sleep | ≈ 1-5 mA | ≈ 2-8 Wochen

Umrechnung: Batteriestrom = (6V×I6V + 5V×I5V) / 3,7V / η, Wirkungsgrad η ≈ 0,9 der MT3608-Booster. Für Spitzen gilt 3,5V (Tiefentladung) und η ≈ 0,85 → deshalb bis ~6A Batteriestrom. Die 3,3V-Verbraucher sind in der 5V-Schiene enthalten (über ESP32-VIN + AMS1117). Vergleich 2S: bei 7,4V wäre der Batteriestrom halb so groß – bei 1S steigt er entsprechend, die Kapazität (37Wh) bleibt dieselbe.

### Ladezeiten (1S 10.000mAh, auf 4,2V, TP4056-Modul)

Ladezeit ≈ Kapazität / Ladestrom × 1,2 (Zusatz für die CV-Phase). Modul-Default: 1A Ladestrom = 0,1C – sehr schonend, volle Ladung in ~12h. Bei 1S entfällt der Zellausgleich komplett.

Stromquelle | Max. Eingang | Ladestrom | Ladezeit | Bewertung
USB 2.0 (PC-Port) | 0,5A / 2,5W | ~0,45A | ~26 h | ohne Erkennung nur 500mA – ungeeignet
USB 3.x (PC-Port) | 0,9A / 4,5W | ~0,85A | ~14 h | geht, langsam
USB-BC Ladesteckdose | 1,5A / 7,5W | 1,0A | ~12 h | ok
Netz-Ladegerät 5V/2,4A | 12W | 1,0A (Modul-Limit) | ~11 h | Empfehlung Klassenzimmer (über Nacht)
USB-C PD (5V/3A) | 15W | 1,0A (Rprog-Limit) | ~11 h | schneller geht nicht ohne Umbau
Rprog angepasst auf 2A | 5V/2A nötig | 2,0A | ~6 h | nur mit starker Quelle – Modul wird warm (≈2,6W Verlust, linearer Lader)
Fazit: Mit dem Modul-Default (1A) dauert eine volle Ladung ~11-12h – ideal über Nacht. Der PC-USB-Port (0,5A) ist mit ~26h unpraktisch. Wärme beachten: TP4056 ist linear, (5V−Akku)×1A ≈ 1,3W Wärme am Modul – belüftet einbauen. Lithium-Sicherheit: nur mit angeschlossener Schaltung laden (DW01A trennt bei Tiefentladung/Überladung/Kurzschluss), Zelle nie unbeaufsichtigt über Nacht am unbekannten Ladegerät betreiben.

## 4.3 Technische Daten (Zusammenfassung)

Parameter | Wert
Prozessor | ESP32-WROOM-32E (2× 240MHz, WiFi 802.11 b/g/n, BT 4.2)
Koprozessor | Arduino Pro Micro (ATmega32U4, 16MHz, 5V)
Verfügbare GPIOs | 34 (10 fest, 24 frei auf Female-Header)
Busse | I²C (IO21/IO22, 400kHz) · SPI (IO18/19/23/26) · GPIO (IO16/17)
Motor-Treiber | DRV8833 Dual H-Bridge (TI): 1,2A/Kanal dau · 2A Spitze, 360mΩ → ~6V am Motor, keine Kühlung nötig
Motor | 2× N20, 6V, 1000RPM, Hall-Encoder
Akku | 1S LiPo 3,7V 10.000mAh (1160100, Fertig-Pack mit PCM), 37Wh, 11×60×100mm
Ladespannung | 4,2V (CC/CV), USB-C 5V Eingang, TP4056-Modul mit DW01A-Schutz
Betriebsspannung | 3,0-4,2V (Akku) → Boost hält konstant 6V (Motor) / 5V (Logik) / 3,3V (Sensoren)
Ladestrom | 1A (0,1C, Modul-Default) · ~11h Ladezeit · optional 2A per Rprog
Max. Stromverbrauch | ≈ 6 A (Batterie, Spitze: Stall + LEDs volle Helligkeit)
Typ. Stromverbrauch | ≈ 1,4 A (Batterie, Dauerfahrt, LEDs gedimmt)
Laufzeit (typisch) | 6-7 Stunden (Dauerfahrt, LEDs gedimmt) · 11h ohne LEDs · 2,7h LEDs volle
Laufzeit (Standby) | ~20-50 Stunden
Bauform (L×B×H) | 160 × 160 × 100 mm
Gewicht | ~800 g
Sensorik vorn | HC-SR04 Ultraschall (3-400cm, ±3mm, 40kHz, Echo-Teiler 10k/20k)
Sensorik seitlich | 2× VL53L0X ToF (30mm-2m, 940nm)
Sensorik Boden | TCS34725 Farbsensor (RGB + Clear)
Sensorik Lage | LSM6DSOX 6-Achsen IMU (Accel ±16g, Gyro ±2000dps)
Anzeige | 0,96" OLED 128×64 + WS2812 LED-Strip 60cm
Datenspeicher | microSD (SPI, bis 32GB)
Kommunikation | WiFi (STA/AP), Bluetooth, I²C, SPI, UART
Programmierung | USB-C (ESP32) + Micro-USB (Arduino), Arduino IDE / PlatformIO
Bauzeit (geschätzt) | 4-8 Stunden pro Roboter (Schüler, mit Anleitung)
Stückpreis (20er-Serie) | ~150-175 € (teure Chassis-Variante bis ~200€) · Gesamtbestellung ~3.000-3.500€

Kettenroboter Konzept V1.0 · Stand 28.09.2026 · Alle Preise Richtwerte inkl. MwSt. · Bestellung: Dezember 2026

Kettenroboter Konzept V1.0 · Stand 28.09.2026

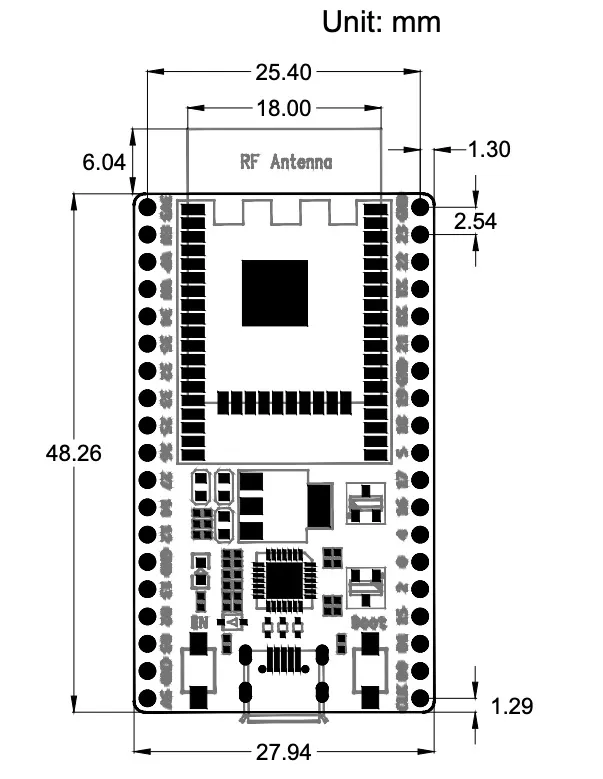
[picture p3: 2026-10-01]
Datenblätter/esp32_devkitc_v4_dimensions.png

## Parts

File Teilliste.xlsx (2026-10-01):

Kategorie | Element | Beschreibung | Stückzahl / Roboter | Gehäuse Typ | Preis | Link
Spannungsregler | MP2338GTL | Lipo auf 5V | 1 | SOT 583 | 0.92 | https://www.mouser.de/de/ProductDetail/Monolithic-Power-Systems-MPS/MP28167GQ-P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
 | MP28167GQ | Lipo auf 6V | 1 | QFN-16 | 1.8 | https://www.mouser.de/de/ProductDetail/Texas-Instruments/TPS61022RWUT
Akku | Lipo | 3,7V 10Ah | 1 | 11x60x100 | 19 | https://www.amazon.de/2P-PH-Anschluss-Wiederaufladbarer-Bluetooth-Lautsprecher-Wearables-Elektronikger%C3%A4te/dp/B0GDTPRDZK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
Micro Controller | "" | Main Controller, 5V auf 3V3 | 1 | 2,54 mm 25,40mm breite, 17 Pins/Reihe | 10 | https://shop.heise.de/esp-32-dev-kit-c-v4
Controller 2 | "" | Motor Steuerung & Tone |  | 34,6 x 18,4 x 4 | 5.5 | https://www.amazon.de/St%C3%BCck-Micro-Modul-Entwicklungsboard-Mikrocontroller-Blue-4-St%C3%BCcke/dp/B0F2DVPVLB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
Motor Controller | DRV8833 | Motor Treiber | 1 | 18,5x16mm (2,54mm pins) | 1.9 | https://www.roboter-bausatz.de/p/2-kanal-drv8833-dc-motor-treiber-modul-3v-10v-1.5a-h-bruecke
Motoren | N20 + Encoder | Motor mit Sensoren | 2 |  | 14 | https://www.amazon.de/St%C3%BCck-Encoder-Getriebemotor-hohem-Drehmoment/dp/B0HJ698766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
I2C verteiler | TCA9548A | IIC MUX, Adresse 0x40 | 1 | 22 x 32 | 2.2 | https://funduinoshop.com/elektronische-module/schnittstellen-konverter/signalwandler/tca9548a-i2c-multiplexer
Ultraschall Sensor | HC-SR04 | / | 1 | 43 x 20 x 15 mm | 3.5 | https://www.reichelt.de/de/de/shop/produkt/entwicklerboards_-_ultraschall_abstandssensor_hc-sr04-161487
Lade Modul | TP4056 | USB-C Eingang | 1 | 28mm x 19mm | 0.2 | https://www.christians-shop.de/Lithium-Akku-Lademodul-1A-mit-Tiefentladungsschutz-25V-TP4056-Ladeschlussspannung-42V
ToF Sensoren | VL53L0X | 3cm-2m Distanz | 2 | 25 x 10,67mm | 4.5 | https://www.roboter-bausatz.de/p/vl53l0x-modul-time-of-flight-laserentfernungsmesser
Gyro sensor | LSM6DSOX | 3 Axen | 1 | 15mm x 25mm | 8 | https://www.amazon.de/ARCELI-MPU-9250-Gyroskop-Beschleunigungssensor-Magnetfeldsensor/dp/B07CDD8B14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
Farbsensor | TCS34725 | Erkennt Farbe / Helligkeit | 1 | 20 × 20 × 3 mm | 7 | https://www.az-delivery.de/en/products/tcs34725-rgb-color-sensor
Display |  | 2,4" 128x64p | 1 | 70 x 48 x 6 mm | 15 | https://www.amazon.de/Fasizi-Display-Modul-serielle-Peripherieschnittstelle/dp/B09Z28KCD3
 |  |  |  |  |  | https://www.otronic.nl/de/2-4-inch-oled-display-128x64-weiss-i2c-ssd1309-3-3v
 |  |  |  |  |  | https://www.waveshare.com/2.42inch-oled-module.htm
SD Karten Reader | SD Module | SPI Bus | 1 | 45 x 24 x 8 mm | 1.5 | https://www.berrybase.de/micro-sd-card-reader-modul-mit-spi-schnittstelle
 |  |  |  |  |  | https://www.amazon.de/Create-idea-St%C3%BCcke-Kartenleser-Streifen/dp/B0DRXBF5RW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
RGB LED STrip | WS2812b | PWM Pin, 5V | 1 | 60cm x 2,7mm | 5 | https://www.ledbe.com/2.7mm-individually-addressable-2812-led-strip
Lautsprecher | Summer | Passiv | 1 | 12 x 8,5 x 8x5 | 0.4 | https://www.amazon.de/Voyoo-elektromagnetischer-Haushaltsger%C3%A4te-Industrieinstrumente-Fitnessger%C3%A4te/dp/B0GHP494N4
Kondensatoren |  |  | 10 |  | 5
 |  |  | 28 |  | 105.42
 |  |  |  |  | / Stück

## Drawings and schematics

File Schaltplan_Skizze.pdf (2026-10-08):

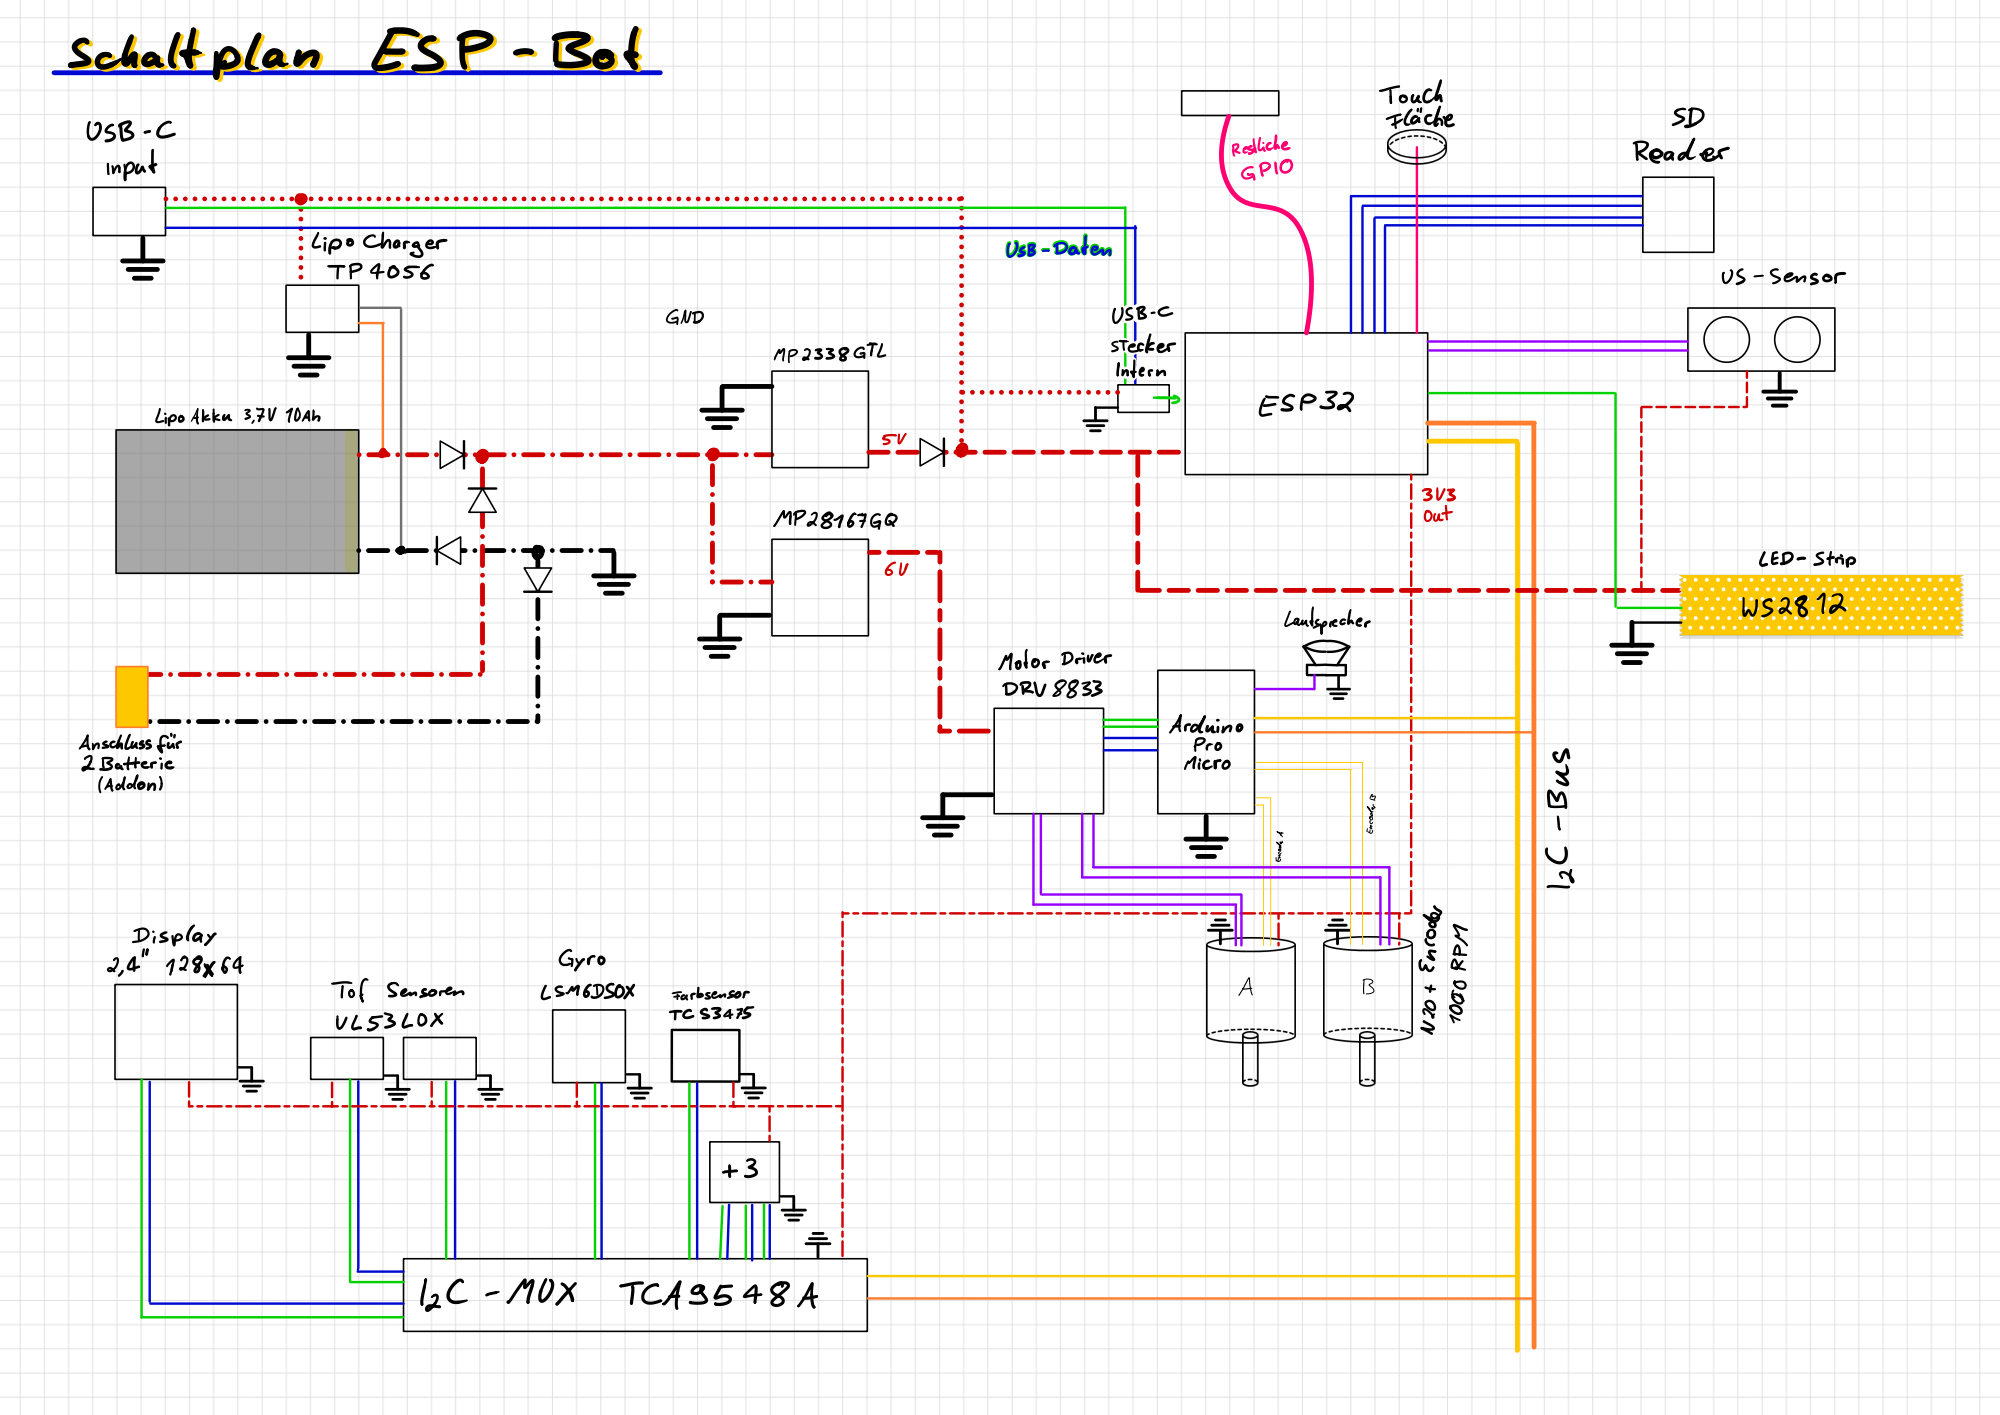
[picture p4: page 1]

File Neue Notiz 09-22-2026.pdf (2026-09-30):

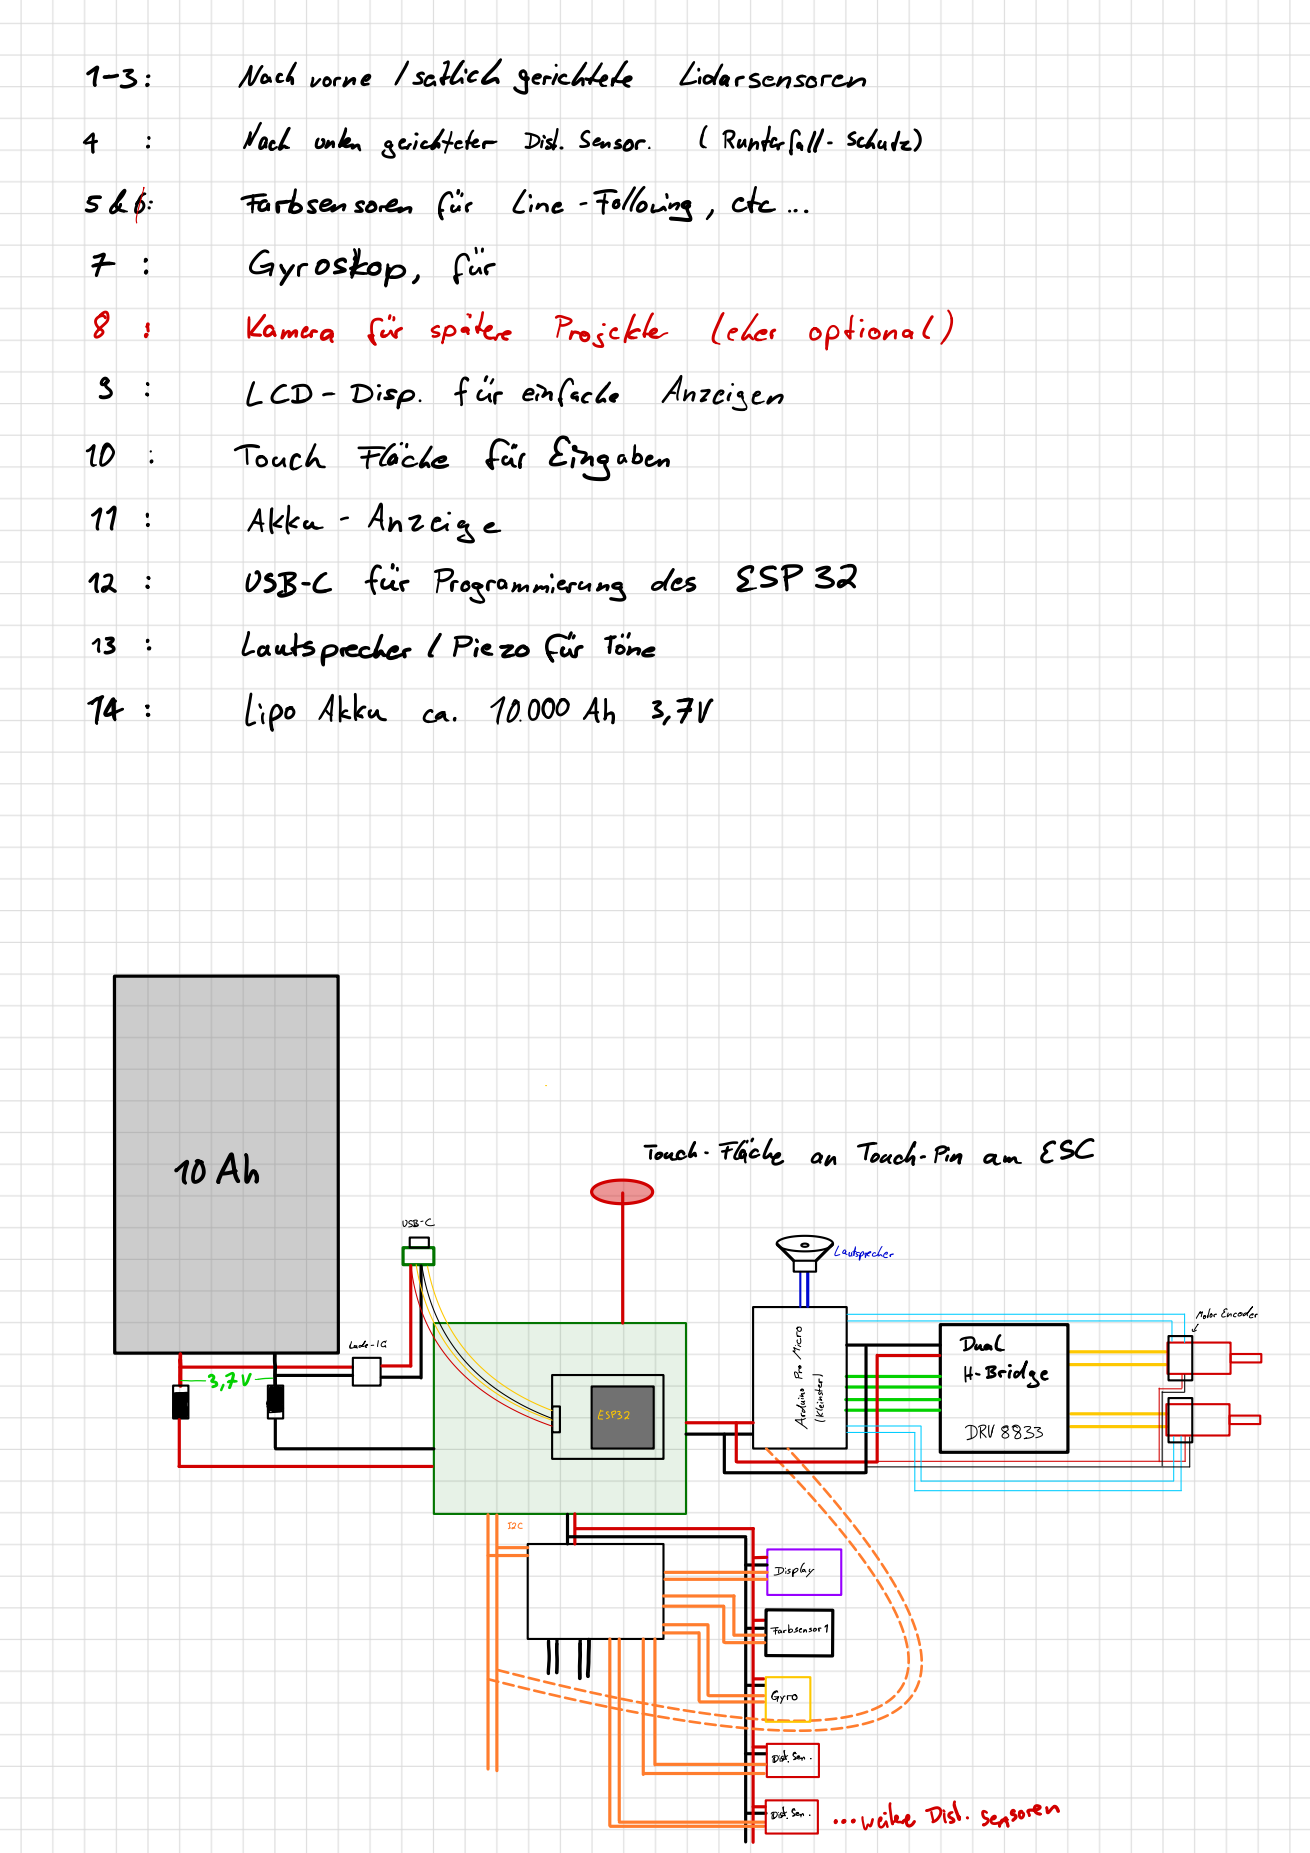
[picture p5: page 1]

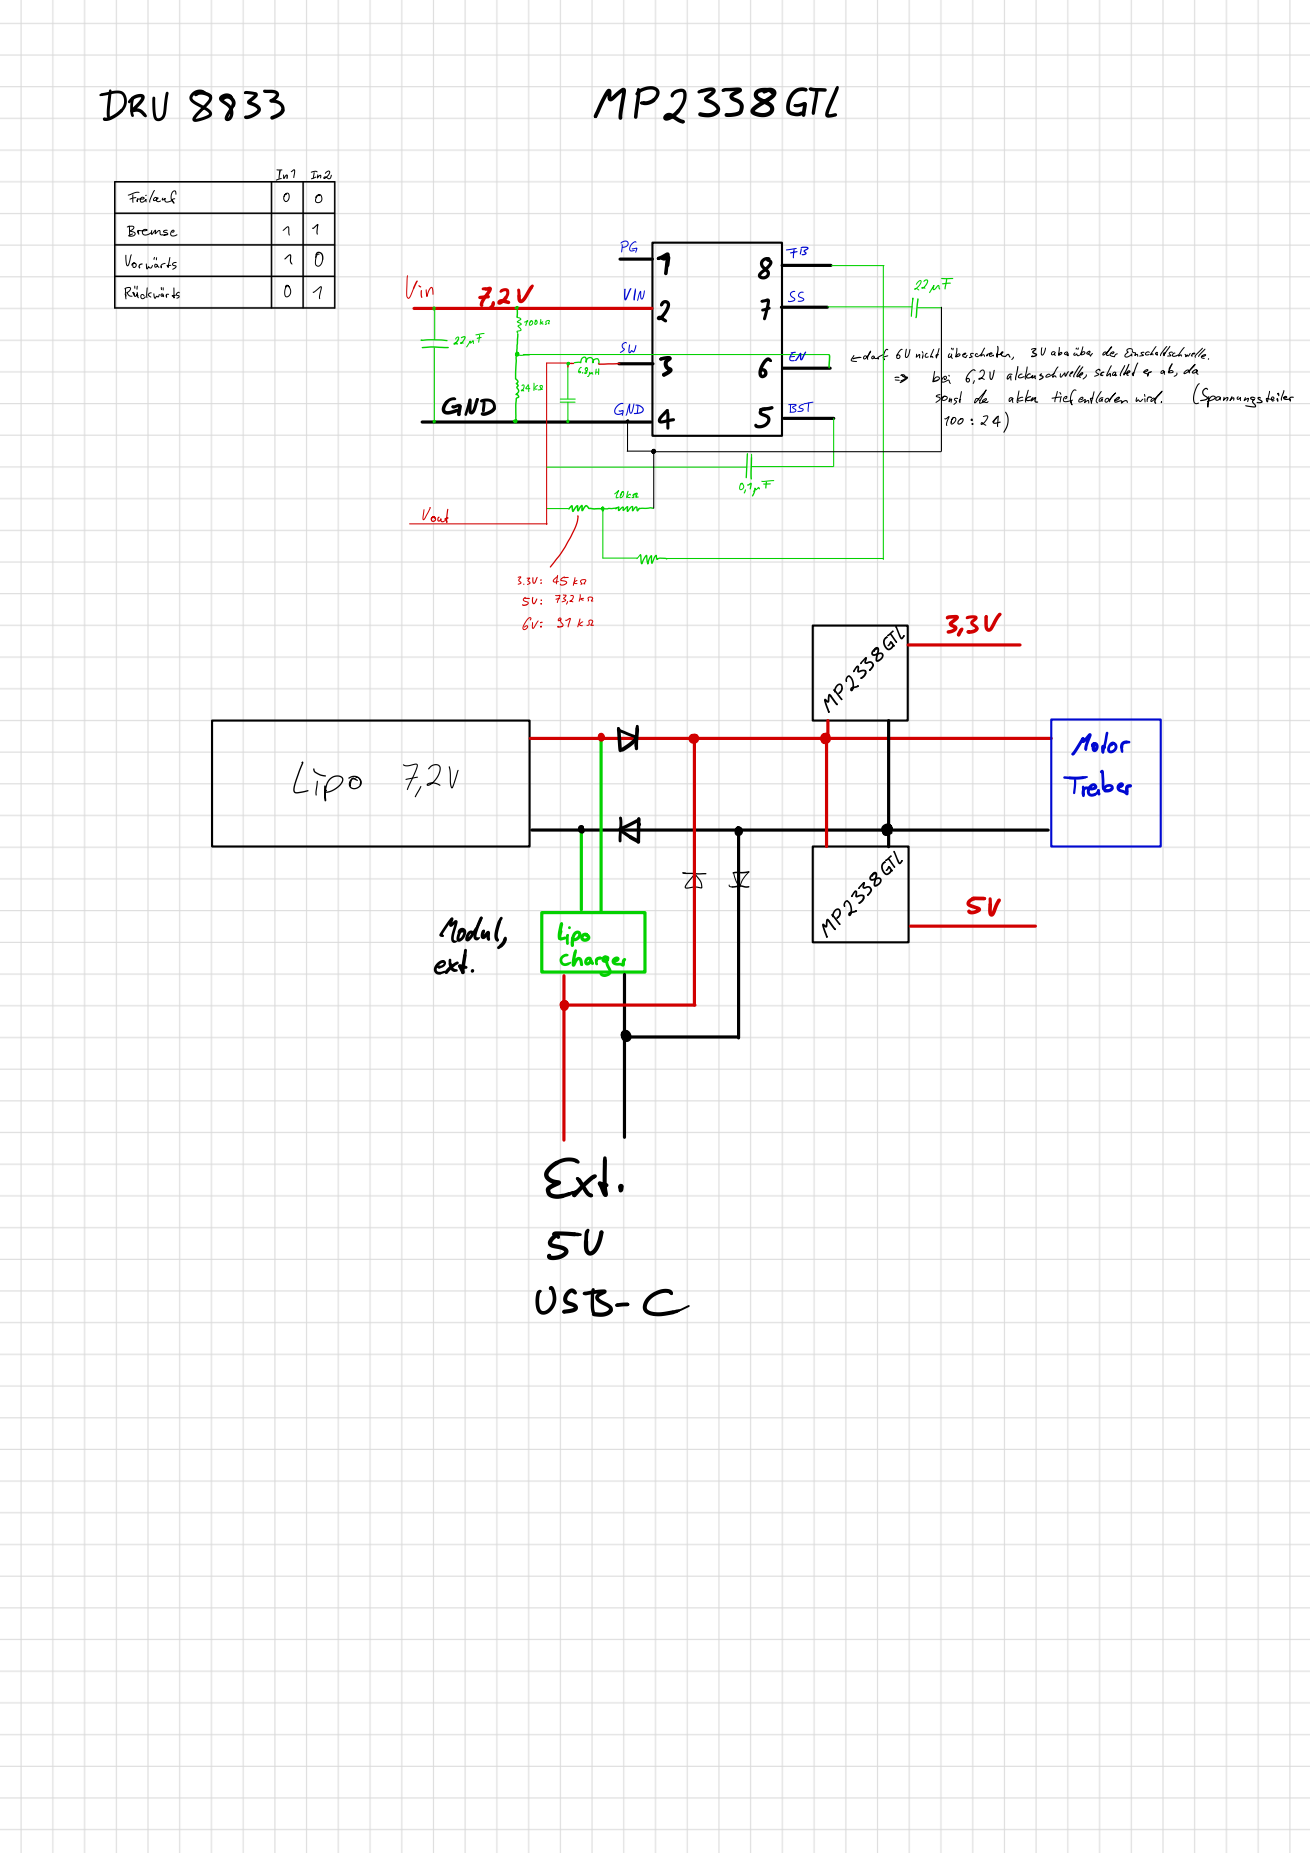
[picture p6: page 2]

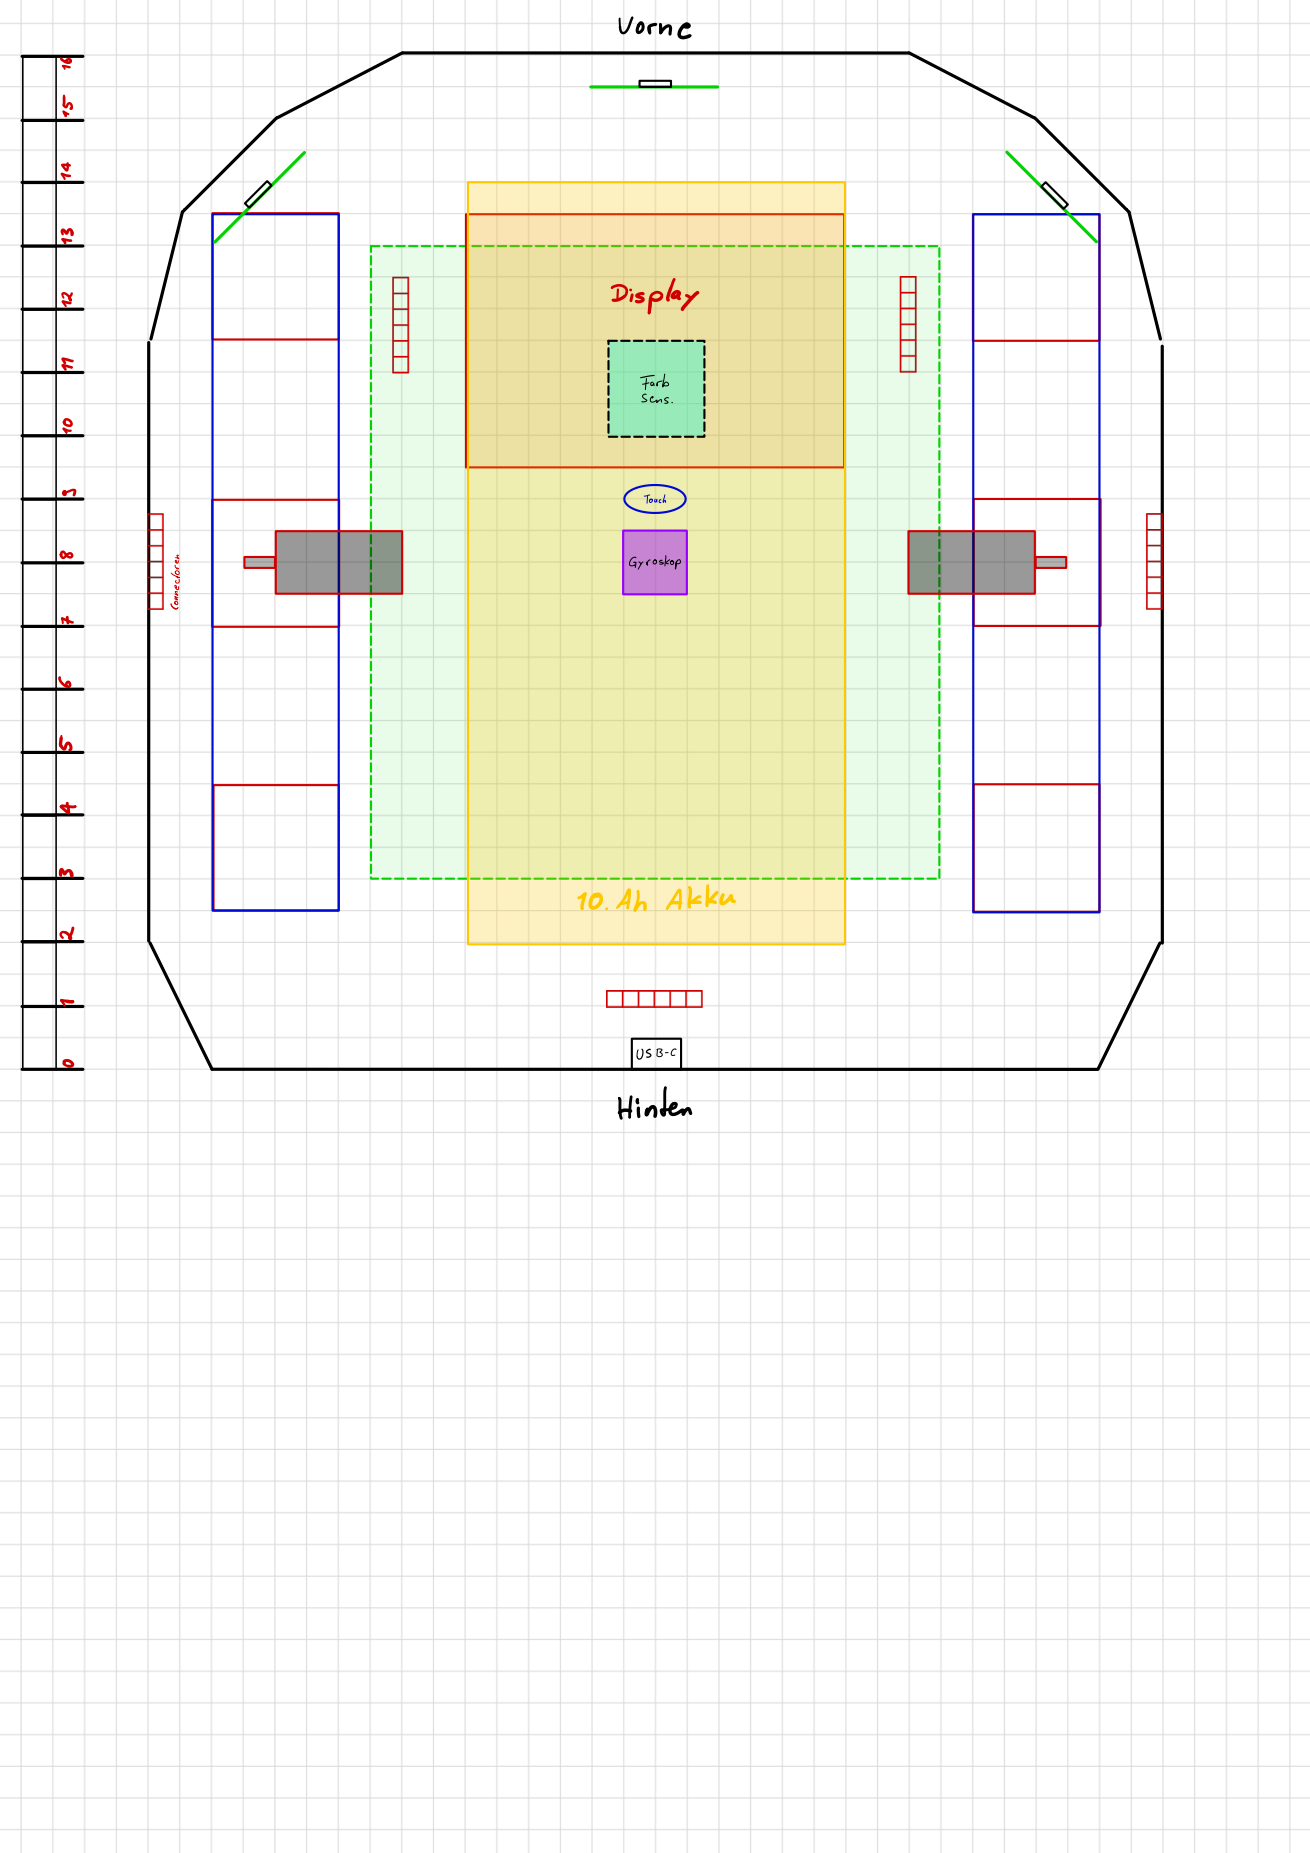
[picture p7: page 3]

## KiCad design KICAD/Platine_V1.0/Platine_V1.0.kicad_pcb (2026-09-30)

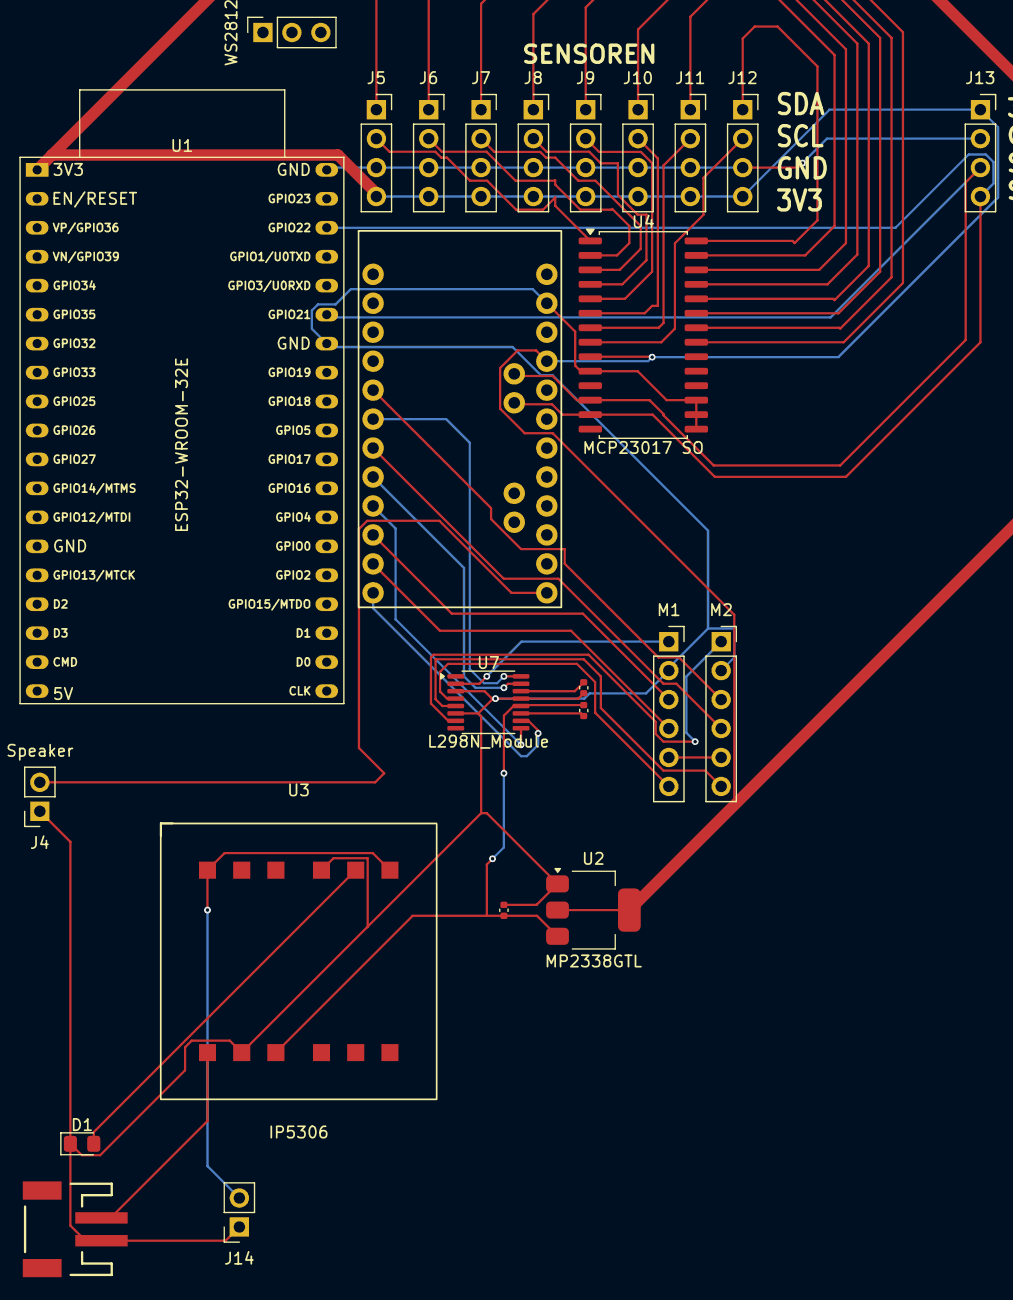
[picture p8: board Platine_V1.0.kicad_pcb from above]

Board: 2 copper layers, 25 parts (0 on the bottom side), 40 nets.

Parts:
C1: 0.1uF; C_0402_1005Metric
C2: 2.2uF; C_0402_1005Metric
C3: 10uF; C_0402_1005Metric
D1: LED; LED_0805_2012Metric_Pad1.15x1.40mm_HandSolder
J1: JST_2mm_LiPo; JST_1x02_P2.0mm_Horizontal_SMD
J4: Speaker; PinSocket_1x02_P2.54mm_Vertical
J5, J6, J7, J8, J9, J10, J11, J12, J13: Conn_01x04_Socket; PinSocket_1x04_P2.54mm_Vertical
J14: Conn_01x02_Socket; PinSocket_1x02_P2.54mm_Vertical
M1, M2: Conn_01x06_Socket; PinSocket_1x06_P2.54mm_Vertical
U1: ESP32-WROOM-32E
U2: MP2338GTL; MP2338GTL_SOT23-5
U3: IP5306; IP5306_Module
U4: MCP23017 SO; L298N_Module
U5: Arduino Pro Mini; Arduino_Pro_Mini_Shield
U7: L298N_Module
WS2812: Conn_01x03_Socket; PinSocket_1x03_P2.54mm_Vertical

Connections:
unnamed: D1.2 (A), U3.5 (CHRG)
unnamed: C2.1, C3.1, D1.1 (K), J1.1 (-), J4.1, J5.3, J6.3, J7.3, J8.3, J9.3, J10.3, J11.3, J12.3, J13.2, J14.1, M1.2, M2.2, U1.14 (GND), U1.32 (GND), U1.38 (GND), U2.1 (GND), U3.4 (GND), U3.8 (BAT-), U4.10 (V_{SS}), U4.15 (A0), U4.16 (A1), U4.17 (A2), U5.23 (GND), U7.3 (AISEN), U7.6 (BISEN), U7.13 (GND), WS2812.3
unnamed: J1.2 (+), U3.7 (BAT+)
unnamed: M1.1, U7.2 (AOUT1)
unnamed: M1.3, U5.10 (D7)
unnamed: M1.4, U5.11 (D8)
unnamed: M1.5, M2.5
unnamed: M1.6, U7.4 (AOUT2)
unnamed: M2.1, U7.7 (BOUT1)
unnamed: M2.3, U5.5 (D2)
unnamed: M2.4, U5.7 (D4)
unnamed: M2.6, U7.5 (BOUT2)
unnamed: J4.2, U5.13 (~D10)
unnamed: J5.1, U4.21 (GPA0)
unnamed: J5.2, U4.1 (GPB0)
unnamed: J6.1, U4.22 (GPA1)
unnamed: J6.2, U4.2 (GPB1)
unnamed: J7.1, U4.23 (GPA2)
unnamed: J7.2, U4.3 (GPB2)
unnamed: J8.1, U4.24 (GPA3)
unnamed: J8.2, U4.4 (GPB3)
unnamed: J9.1, U4.25 (GPA4)
unnamed: J9.2, U4.5 (GPB4)
unnamed: J10.1, U4.26 (GPA5)
unnamed: J10.2, U4.6 (GPB5)
unnamed: J5.4, J6.4, J7.4, J8.4, J9.4, J10.4, J11.4, J12.4, J13.1, U1.1 (3V3), U2.2 (VO), U4.9 (V_{DD}), U5.21 (VCC)
unnamed: J11.1, U4.27 (GPA6)
unnamed: J11.2, U4.7 (GPB6)
unnamed: J12.1, U4.28 (GPA7)
unnamed: J12.2, U4.8 (GPB7)
unnamed: J13.3, U1.33 (GPIO21), U4.12 (SCK), U5.28 (A5/SCL)
unnamed: J13.4, U1.36 (GPIO22), U4.13 (SDA), U5.27 (A4/SDA)
unnamed: J14.2, U3.1 (VBUS), U3.6 (WAKE)
unnamed: C1.2, C3.2, U1.35 (U0TXD/GPIO1), U2.3 (VI), U3.9 (LOAD), U7.12 (VM), WS2812.1, WS2812.2
unnamed: U5.6 (~D3), U7.16 (AIN1)
unnamed: U5.8 (~D5), U7.15 (AIN2)
unnamed: U5.9 (~D6), U7.9 (BIN1)
unnamed: U5.12 (~D9), U7.10 (BIN2)
unnamed: C1.1, U7.11 (VCP)
unnamed: C2.2, U7.14 (VINT)

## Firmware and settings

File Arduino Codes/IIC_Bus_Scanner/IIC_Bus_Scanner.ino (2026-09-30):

#include <Wire.h>

#define SDA_PIN 15
#define SCL_PIN 16

#define MUX_ADDRESS 0x70

#define SCAN_INTERVAL 2000

const char* deviceName(uint8_t addr) {
  switch (addr) {
    case 0x70: return "PCA9548A (Mux)";
    case 0x3C: return "SSD1306 OLED (Adresse 0x3C)";
    case 0x3D: return "SSD1306 OLED (Adresse 0x3D)";
    case 0x68: return "MPU6050 GY-521 (AD0=GND)";
    case 0x69: return "MPU6050 GY-521 (AD0=VCC)";
    default: return "unbekannt";
  }
}

bool muxSelect(uint8_t channel) {
  Wire.beginTransmission(MUX_ADDRESS);
  Wire.write(1 << channel);
  return Wire.endTransmission() == 0;
}

bool probeDevice(uint8_t address) {
  Wire.beginTransmission(address);
  return Wire.endTransmission() == 0;
}

void printHeader() {
  Serial.println();
  Serial.println(F("############################################"));
  Serial.println(F("#        I2C Bus-Scanner PCA9548A          #"));
  Serial.println(F("#  prueft Mux, alle Kanaele und Adressen   #"));
  Serial.println(F("############################################"));
}

void scanChannel(uint8_t channel) {
  Serial.print(F("Kanal "));
  if (channel < 10) Serial.print(F(" "));
  Serial.print(channel);
  Serial.print(F("  |  "));

  if (!muxSelect(channel)) {
    Serial.println(F("Kanal nicht waehlbar (Mux-Fehler)"));
    return;
  }

  uint8_t found[127];
  uint8_t count = 0;

  for (uint8_t addr = 0x08; addr < 0x78; addr++) {
    if (probeDevice(addr)) {
      found[count++] = addr;
    }
  }

  if (count == 0) {
    Serial.println(F("keine Geraete"));
  } else {
    for (uint8_t i = 0; i < count; i++) {
      Serial.print(F("0x"));
      if (found[i] < 0x10) Serial.print(F("0"));
      Serial.print(found[i], HEX);
      Serial.print(F(" ("));
      Serial.print(deviceName(found[i]));
      Serial.print(F(")  "));
    }
    Serial.println();
  }
}

void scanAll() {
  Serial.println();
  Serial.println(F("Adressen-Scan gestartet..."));

  if (!probeDevice(MUX_ADDRESS)) {
    Serial.println(F("[FEHLER] PCA9548A (0x70) nicht erreichbar!"));
    Serial.println(F("[HINWEIS] Pruefen: Strom, GND, SDA=Pin21, SCL=Pin22,"));
    Serial.println(F("          Pull-Up-Widerstaende, A0-A2 Jumper = GND"));
    return;
  }

  Serial.println(F("[OK] PCA9548A erkannt unter 0x70"));
  Serial.println();

  for (uint8_t ch = 0; ch < 8; ch++) {
    scanChannel(ch);
  }

  Serial.println();
  Serial.println(F("Zusammenfassung der gefundenen Geraete:"));
  Serial.println(F("  Bus-Selbstadresse (immer): 0x70 -> PCA9548A Mux"));
  Serial.println(F("  Kanal 0 erwartet:          0x3C/0x3D -> SSD1306 OLED"));
  Serial.println(F("  Kanal 4 erwartet:          0x68/0x69 -> MPU6050 GY-521"));
  Serial.println(F("------------------------------------------------------"));
}

void setup() {
  Serial.begin(115200);
  delay(200);
  Wire.begin(SDA_PIN, SCL_PIN);
  printHeader();
}

void loop() {
  scanAll();
  Serial.println();
  Serial.print(F("Naechster Scan in "));
  Serial.print(SCAN_INTERVAL / 1000);
  Serial.println(F(" s..."));
  delay(SCAN_INTERVAL);
}

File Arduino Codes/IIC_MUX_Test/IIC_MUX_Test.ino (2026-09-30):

#include <Wire.h>

#define SDA_PIN 15
#define SCL_PIN 16

#define MUX_ADDRESS 0x70

void setup() {
  Serial.begin(115200);
  delay(200);
  Serial.println(F("=== PCA9548A MUX-Test ==="));
  Serial.println(F("[INFO] Erwartete Adresse: 0x70 (A0=A1=A2=GND)"));

  Wire.begin(SDA_PIN, SCL_PIN);

  pinMode(SDA_PIN, INPUT_PULLUP);
  pinMode(SCL_PIN, INPUT_PULLUP);
  delay(20);
  Serial.print(F("[TEST] SDA-Pegel im Ruhezustand: "));
  Serial.println(digitalRead(SDA_PIN) ? F("HIGH (ok)") : F("LOW (!)"));
  Serial.print(F("[TEST] SCL-Pegel im Ruhezustand: "));
  Serial.println(digitalRead(SCL_PIN) ? F("HIGH (ok)") : F("LOW (!)"));
  if (digitalRead(SDA_PIN) == LOW) {
    Serial.println(F("[FEHLER] SDA wird auf LOW gehalten - Bus haengt!"));
    Serial.println(F("[HINWEIS] Ein Modul haelt die Leitung oder Kurzschluss:"));
    Serial.println(F("          Mux/OLED/Gyro einzeln nacheinander ABstecken"));
    Serial.println(F("          und testen. Fehlerhaftes Modul identifizieren."));
  }
  if (digitalRead(SCL_PIN) == LOW) {
    Serial.println(F("[FEHLER] SCL wird auf LOW gehalten"));
  }

  uint8_t addr = 0x70;
  Wire.beginTransmission(addr);
  uint8_t result = Wire.endTransmission();

  if (result == 0) {
    Serial.println(F("[OK] MUX antwortet an 0x70!"));
    Serial.println(F("[TEST] Lese Mux-Register..."));
    Wire.requestFrom(addr, (uint8_t)1);
    if (Wire.available()) {
      uint8_t reg = Wire.read();
      Serial.print(F("[OK] Registerinhalt: 0x"));
      Serial.println(reg, HEX);
    }

    Serial.println(F("[TEST] Kanal 0 auswaehlen..."));
    Wire.beginTransmission(addr);
    Wire.write(0x01);
    if (Wire.endTransmission() == 0) {
      Wire.requestFrom(addr, (uint8_t)1);
      if (Wire.available()) {
        uint8_t reg = Wire.read();
        Serial.print(F("[OK] Register nach Kanal 0: 0x"));
        Serial.println(reg, HEX);
      }
    }

    Serial.println(F("[TEST] Kanal 4 auswaehlen..."));
    Wire.beginTransmission(addr);
    Wire.write(0x10);
    if (Wire.endTransmission() == 0) {
      Wire.requestFrom(addr, (uint8_t)1);
      if (Wire.available()) {
        uint8_t reg = Wire.read();
        Serial.print(F("[OK] Register nach Kanal 4: 0x"));
        Serial.println(reg, HEX);
      }
    }

    Wire.beginTransmission(addr);
    Wire.write(0x00);
    Wire.endTransmission();

    Serial.println(F("[OK] MUX funktioniert (Lesen+Schreiben+Kanalwahl OK)"));
  } else {
    Serial.print(F("[FEHLER] Kein Antwort an 0x70, Wire-Fehlercode: "));
    Serial.println(result);
    Serial.println(F("[HINWEIS] Pruefen:"));
    Serial.println(F("  1) Mux auf 3.3V, GND verbinden"));
    Serial.println(F("  2) SDA->P15, SCL->P16 (nicht vertauscht)"));
    Serial.println(F("  3) A0, A1, A2 wirklich auf GND"));
    Serial.println(F("  4) Pull-Ups auf SDA/SCL vorhanden"));
    Serial.println(F("  5) Modul hat evtl. andere Adresse -> pruefe 0x71-0x77"));

    Serial.println(F("[INFO] Scan 0x70-0x77 (alle A0-A2 Kombinationen):"));
    for (uint8_t a = 0x70; a <= 0x77; a++) {
      Wire.beginTransmission(a);
      if (Wire.endTransmission() == 0) {
        Serial.print(F("[OK] MUX gefunden an 0x"));
        Serial.println(a, HEX);
      }
    }
  }
}

void loop() {
  delay(2000);
}

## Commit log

2026-09-30 Anlegen eines Github Repositorys mit den bisherigen Erungenschaften
    [Platine_V1.0.kicad_pcb, Platine_V1.0.kicad_sch]
2026-10-01 Preisliste Hinzugefügt - ca. 110€/Roboter
    [Teilliste.xlsx]
2026-10-08 Neuer Schaltplan, der die Verkabelung als Idee Zeigt.
2026-10-08 KI-Auflistung der ESP32 Modelle, und dessen Funktionen (+empfehlung für dieses Projekt)
